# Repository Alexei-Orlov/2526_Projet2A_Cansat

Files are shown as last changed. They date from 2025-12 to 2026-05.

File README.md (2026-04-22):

# 🛰️CanSat 2025-2026
   
> **ENSEA's CanSat team project for the 2025–2026 C'space edition**

We are a team of of second year engeneering students at ENSEA and we will attend the 2025-2026 edition of the CanSat competition. CanSat competitions challenge teams to design, build, and launch a can-sized (33 cl) satellite that completes scientific or engineering missions during descent.

This year's missions are listed below :

- **Main Mission (Mandatory)**
   - **Mission 1: Deployment and Landing**
       - **Integration**: The CanSat must be equipped with a parachute located inside the device, designed to deploy during flight.
       - **Deployment**: The CanSat must successfully deploy its parachute at an altitude between 75 and 90 meters.

- **Secondary Missions (Optional)**
    - **Mission 2: Downsizing**
    **Reducing** the CanSat to a 33cl format will allow the team to double its score on the technical section.

    - **Mission 3: Ground Study**
    Conduct a study of a topographical feature during the flight.

    - **Mission 4: Onboard Camera**
    Record a video of the parachute deployment or the CanSat’s landing.

- **Bonus Mission**
    -  During the descent or following the landing, the CanSat may perform an additional mission. Its evaluation will be at the jury's discretion. It must be validated by the controllers during the RCE1 to ensure compliance with the rules.

And finally, here's the list of team members and their roles :

| Name | Role |
|---|---|
| Alexeï DOUILLARD | 3D Modeling, Satellite integration, PCB |
| Juan Pablo BARONA CIFUENTES | Embedded systems, firmware |
| Ted KOYAZANDE | Ground Station, Communications |
| Amr TAOUIS | PCB Design and testing |
| Abdelmoughit HAJJI LAAMOURI | Code |

---

## 📋 Objective 

We then defined our own objectives based on the missions we chose to fulfill among the previously mentionned missions. 

- **Main Mission (Mandatory)**
  - Devise a kirigami inspired drogue chute which will act as a protective cap on the CanSat. It will be used to deploy the main parachute. The drogue chute will be released thanks to a string and an elastic band tied to a servomotor we want to test it with the help of a homemade wind tunnel.

- **Secondary Missions**
  - **Mission 2** : Downsizing
    - Fit everything under a 330mL limit and a 350g limit using a 6 layered PCB and a super lightweight parachute
  
  - **Mission 3** : Ground study
    - **Plan A** : (Currently active)
      Use a 100m time of flight (TOF) sensor to map the ground.
      Induce a rotation thanks to an helicoïdal-shaped can.
      Precisely place the mapped point with the help of an Inertial Measurment Unit (IMU) and a barometer. The wind tunnel will also help desinging the shape of the can to see if it spins.
    - **Plan B** :
      Use a high resolution camera to film the whole descent
      Create a topological map thanks to an AI after the mission.
  - **Mission 4: Onboard Camera**
    - Record the landing using a small independent mini camera.
- **Bonus Mission**
  - Display some of the recorded data of the descend to the ground station within the transmition rate of our LoRa module.

## 🔧 Development

The development section is divided in 4 parts:
- Block diagram
- Explanation of components
- Technical sections
- Used software

So first, it's required to show the Block diagram of the solution to understand how the project is being developed.

### 💡 Block diagram of the solution

<div align="center">
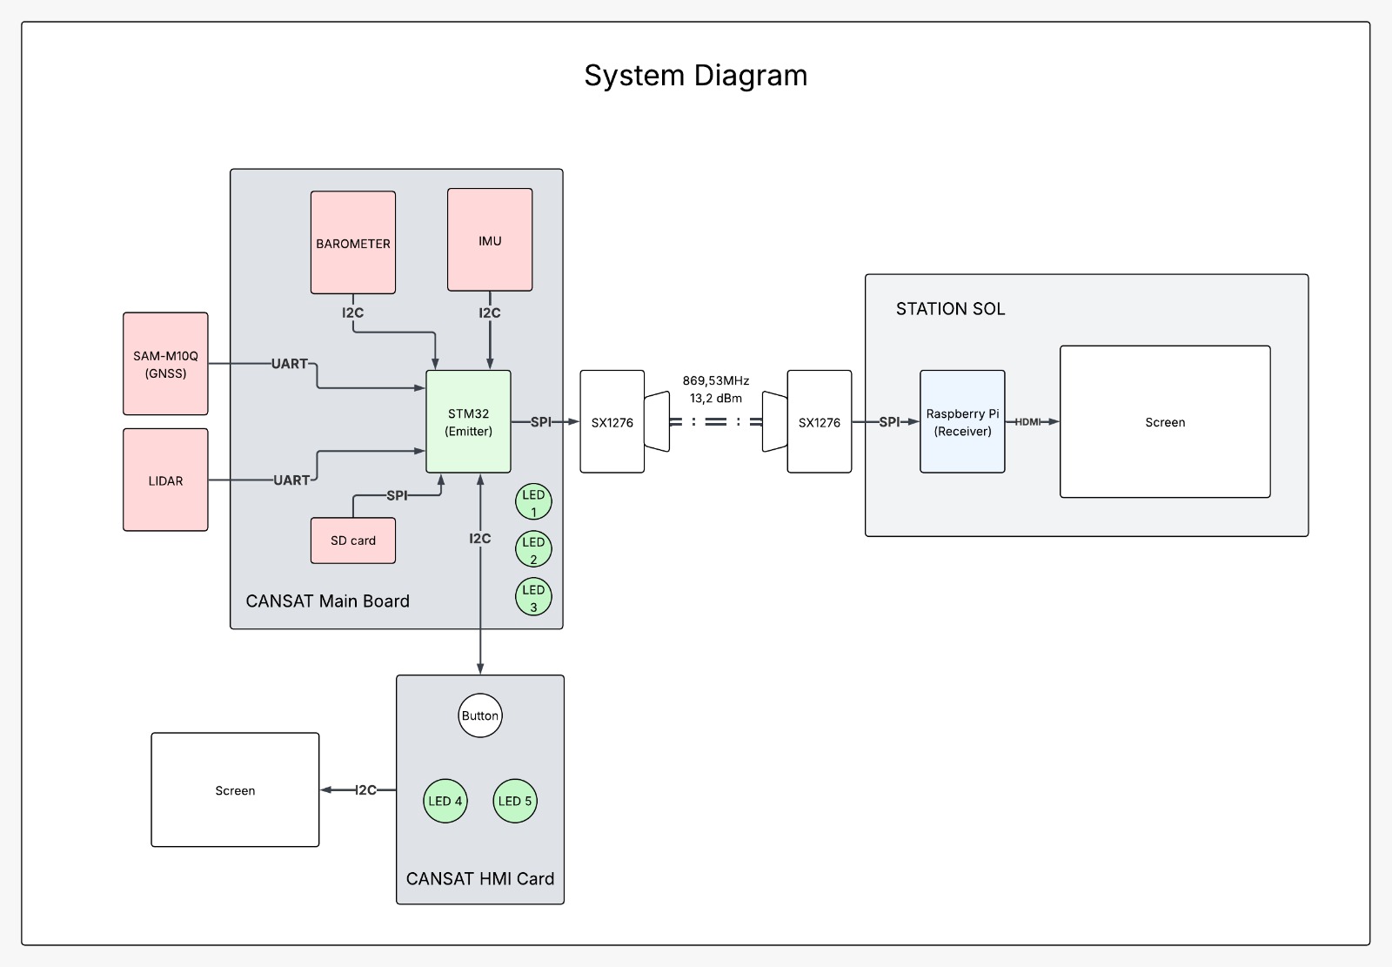
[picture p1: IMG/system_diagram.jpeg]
System Diagram
  <br><br>
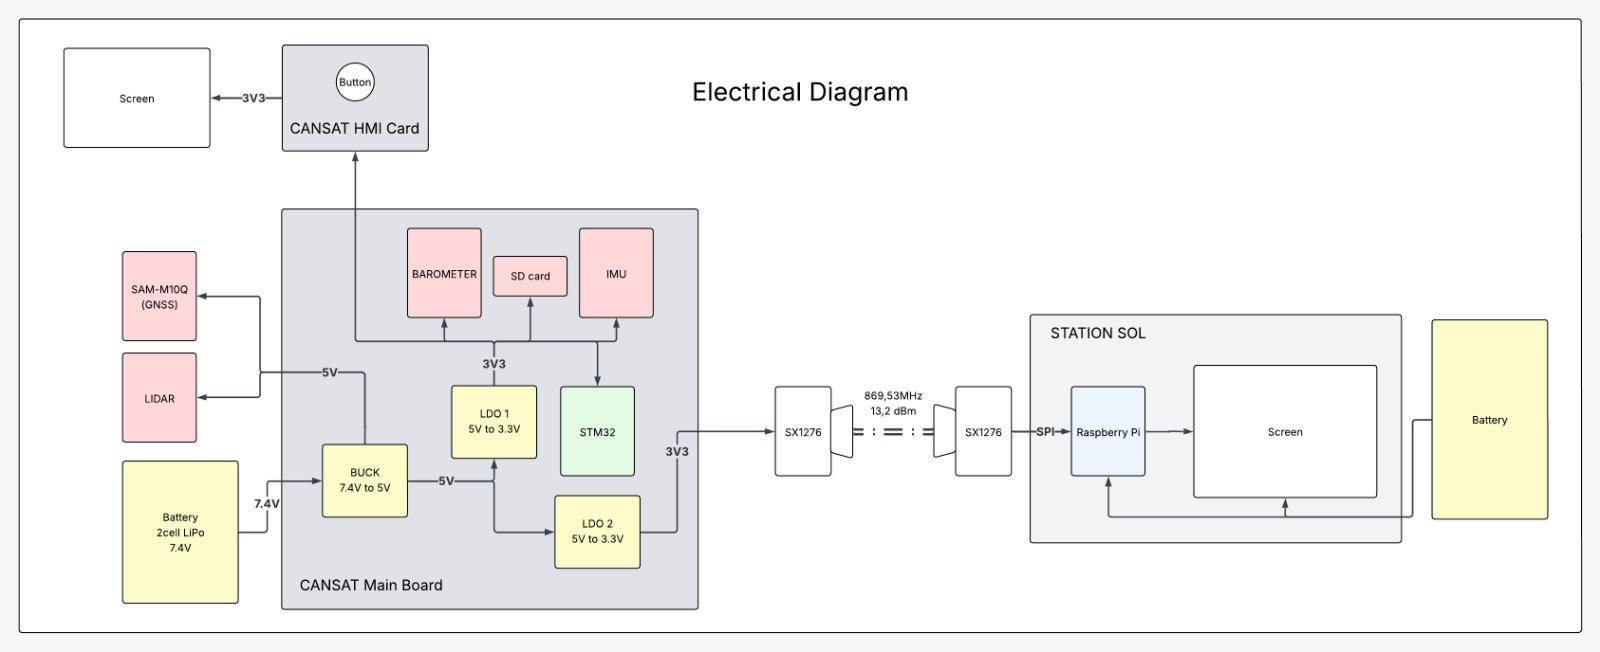
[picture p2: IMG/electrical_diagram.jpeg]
Electrical Diagram
  
</div>

### 🔗 Used components description

All the blocks shown above will be implemented with the components listed below.

| Component | Reference | Description | Justification |
| :--- | :--- | :--- | :--- |
| **LoRa Module** | SX1276 | The SX1276/77/78/79 transceivers feature the LoRaTM long range modem that provides ultra-long range spread spectrum communication and high interference immunity whilst minimising current consumption. | Long range communications were required with a solid reliable interface, also it was recommended by last year’s CANSAT team from the school. | On the Mainboard PCB
| **LiDAR Altimeter** | LW20/C | A compact, IP67-rated laser altimeter from LightWare. It provides high-precision distance measurements up to 100 meters using time-of-flight technology, capable of multiple returns. | It allows accurate terrain mapping to accomplish one of the missions. |
| **Microcontroller (MCU)** | STM32G431CBU6 | A 32-bit ARM Cortex-M4 microcontroller by STMicroelectronics. It features mixed-signal capabilities, high-speed processing (170 MHz), and hardware mathematical accelerators (CORDIC/FMAC). | High processing speed is required for sensor fusion and real-time control loops, handling data faster and more efficiently than standard beginner boards. |
| **Barometer** | BMP581 | A high-precision absolute barometric pressure sensor. It is designed for mobile applications, offering low noise and low power consumption to measure atmospheric pressure. | Determining altitude and vertical velocity (descent rate). It is critical for triggering parachute deployment based on pressure changes. Also recommended from last year’s project. |
| **IMU (Inertial Measurement Unit)** | BNO055 | A 9-axis System in Package (SiP) integrating a triaxial 14-bit accelerometer, a triaxial 16-bit gyroscope with a range of ±2000 degrees per second, and a triaxial geomagnetic sensor. It includes a dedicated microcontroller for sensor fusion. | Provides orientation data (Euler angles, Quaternions) directly. The on-board sensor fusion offloads complex math from the main MCU, ensuring accurate angular position estimation. |
| **GNSS Module** | SAM-M10Q | A patch antenna module from u-blox featuring the M10 standard precision GNSS platform. It supports concurrent reception of four GNSS constellations (GPS, GLONASS, Galileo, and BeiDou). | Required for tracking the CanSat's trajectory and lateral movement. The concurrent reception ensures a faster "time-to-first-fix" and better positioning accuracy. Also provides redundancy for altitude estimation. |
| **Voltage Regulator (LDO)** | LDO40LPU33RY | A high-precision, low-dropout voltage regulator from STMicroelectronics. It provides a stable output with low quiescent current and low noise. | Used to provide a clean, stable 3.3V power line to sensitive electronics (like the MCU and sensors) filtering out noise that might come from the main power rail. |
| **Local Storage** | Micro SD Card + Molex 473092651 | A standard high-capacity non-volatile flash memory storage card interfaced via SPI or SDIO with the Molex 473092651 card reader. | Used to save a large amount of points and telemetry from the different sensors. It will be recording everything and setting timestamps on measurements. This will be the data that is recovered post-flight. |
| **Single Board Computer** | Raspberry Pi (Model 4 / Zero 2 W) | A low-cost, credit-card-sized computer that plugs into a computer monitor or TV, and uses a standard keyboard and mouse. It runs a Linux-based operating system. | Utilized for the Ground Station architecture. It processes the incoming telemetry stream, handles the graphical user interface (GUI) for data visualization, and stores mission logs. |
| **Battery** | 2-Cell LiPo (7.4V) 2 x 500mAh| A Lithium Polymer rechargeable battery pack consisting of two cells in series, providing a nominal voltage of 7.4V and high discharge capabilities. | The 7.4V output is ideal for the input range of the voltage regulators, providing sufficient overhead to maintain stable power throughout the mission duration. |
| **Buck Converter** | LMR51625 | A wide-input, synchronous buck converter from Texas Instruments. It is designed to regulate high voltage inputs down to lower logic levels with high efficiency and a compact footprint. | Steps down the 7.4V battery voltage to 5V efficiently. Unlike linear regulators, this switching regulator minimizes heat generation and power loss. |
| **JST Connectors** | JST SH Vertical| Small plugin connector we used sizes from 3 to 7 pins, Thanks JST for the samples ! | All of our components are connected thanks to JST SH connectors these are a good compromise between compactness and ease of use |
| **Camera** | Drone camera| Camera module stolen from a drone with 2.4GHz reciever and SD card reader plugged to another 500mAh 3.4V battery | We found 2 very similar HD cameras from cheap drones however one only works via a wifi app and the other one via UART|
### 🔌 Electronic design
#### Mainboard PCB
The electronic architecture of the Vortex project is based on a “reverse engineering” process. Indeed, by analyzing and understanding last year’s project and more precisely last year’s PCB, we were able to identify the key points of the PCB and the components that needed to be modified. Due to this process, we chose all the components listed above to meet the evolving requirements of our missions and did the schematic.

<div align="center">
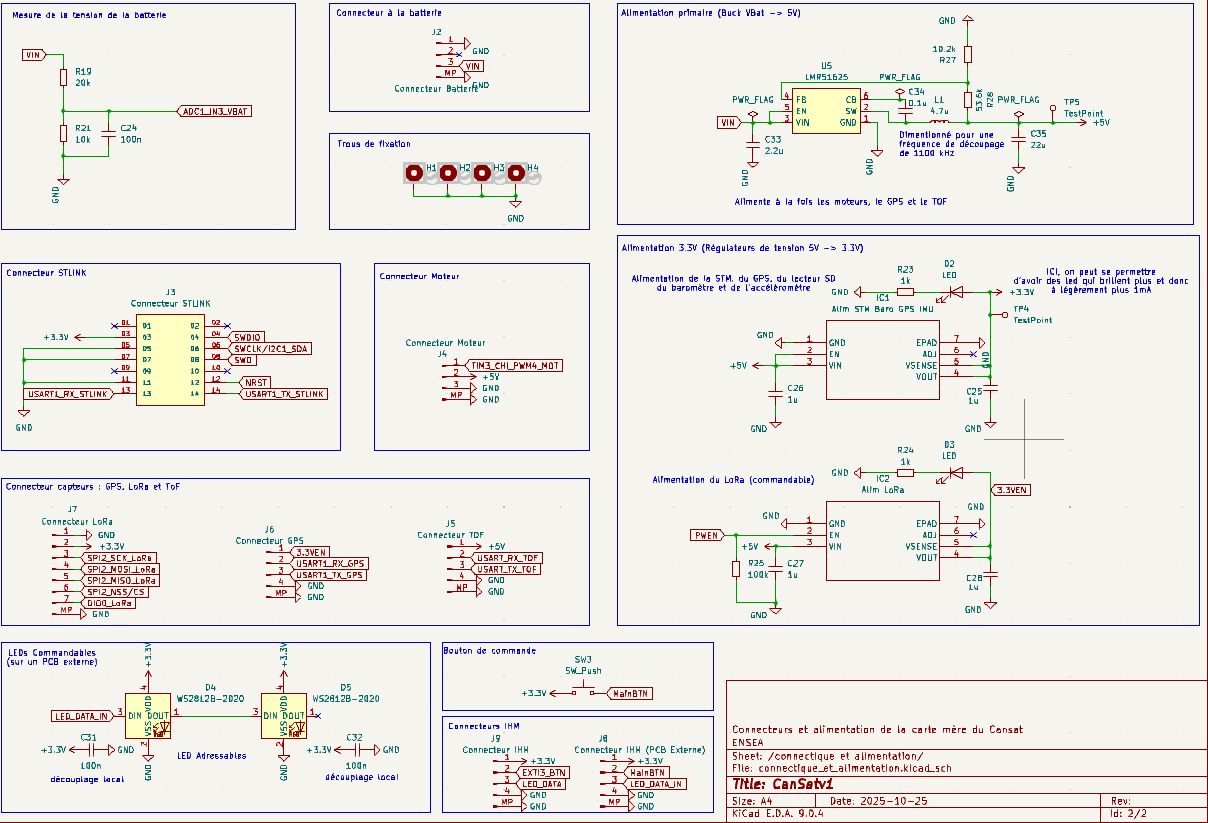
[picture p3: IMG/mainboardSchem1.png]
Schematic 1
  <br><br>
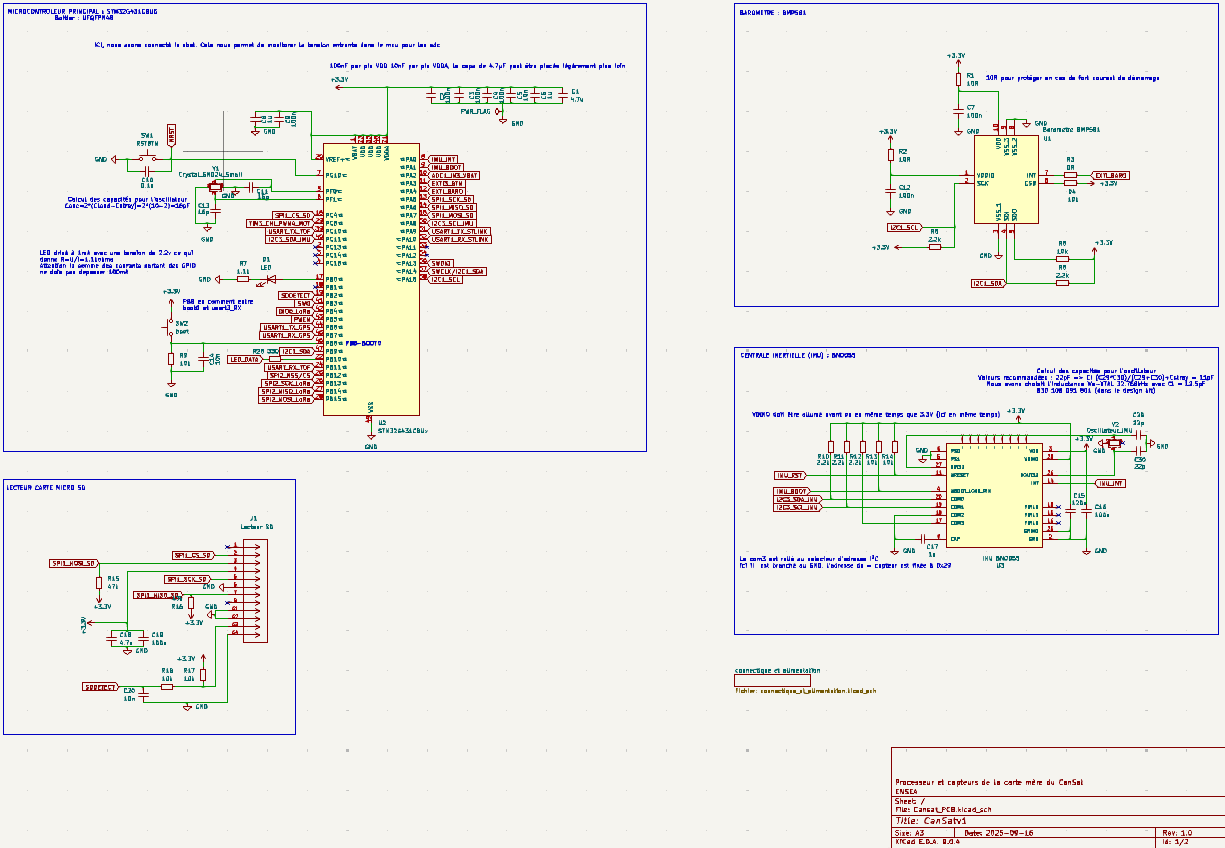
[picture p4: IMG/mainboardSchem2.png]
Schematic 2
  
</div>

To integrate this high quantity of components within the restricted 33cl volume of the can, we developed a 6-layer PCB. The layers are organised as follows : 
1. Signal
2. GND
3. Signal
4. PWR
5. GND
6. Signal

Here is the final PCB :

<div align="center">
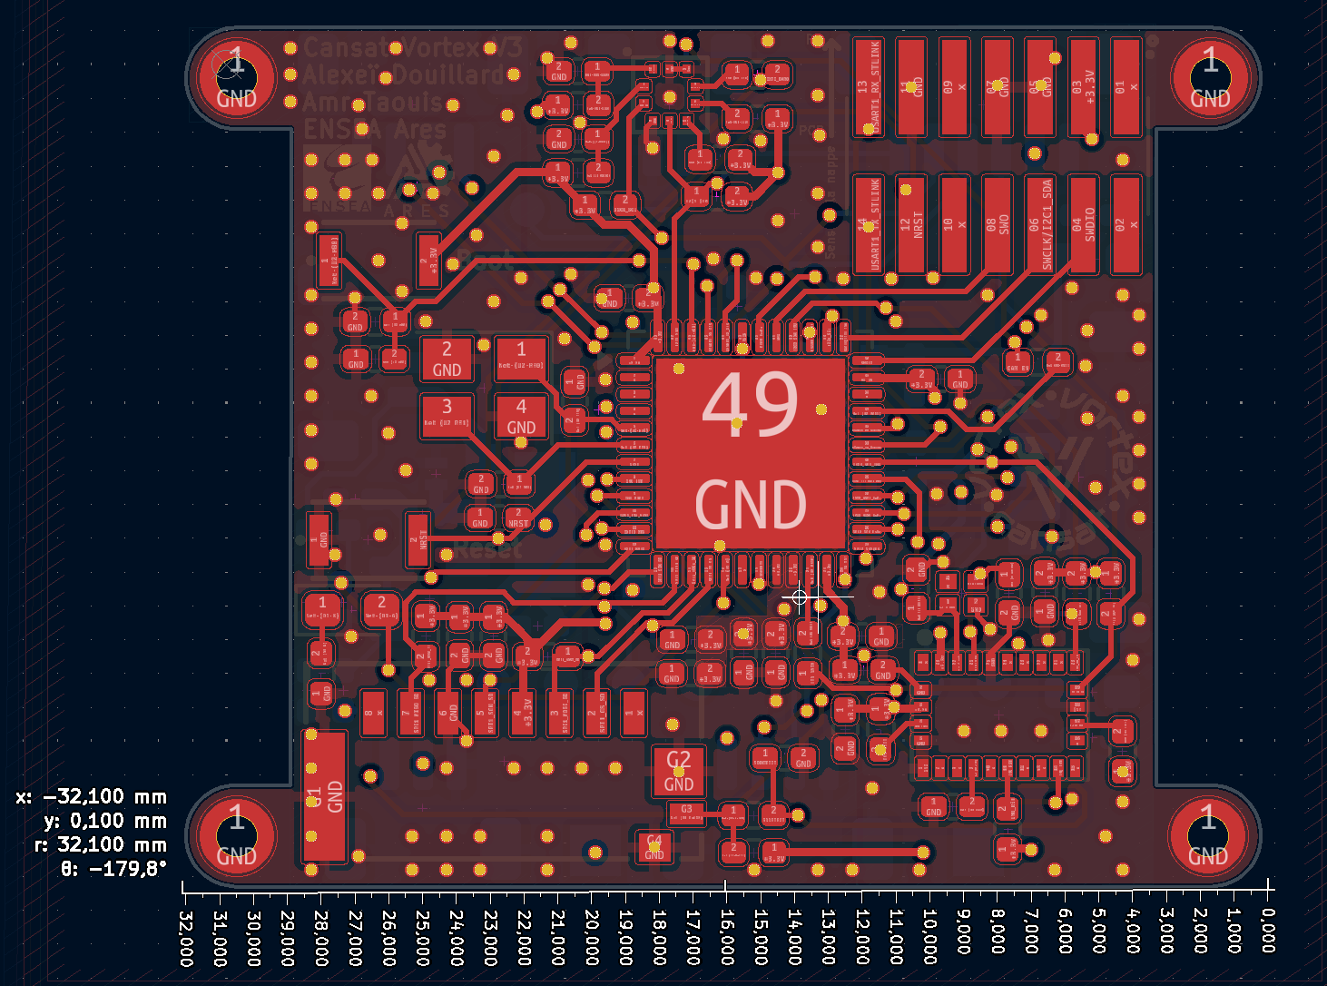
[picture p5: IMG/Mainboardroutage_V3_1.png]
Mainboard Top
  <br><br>
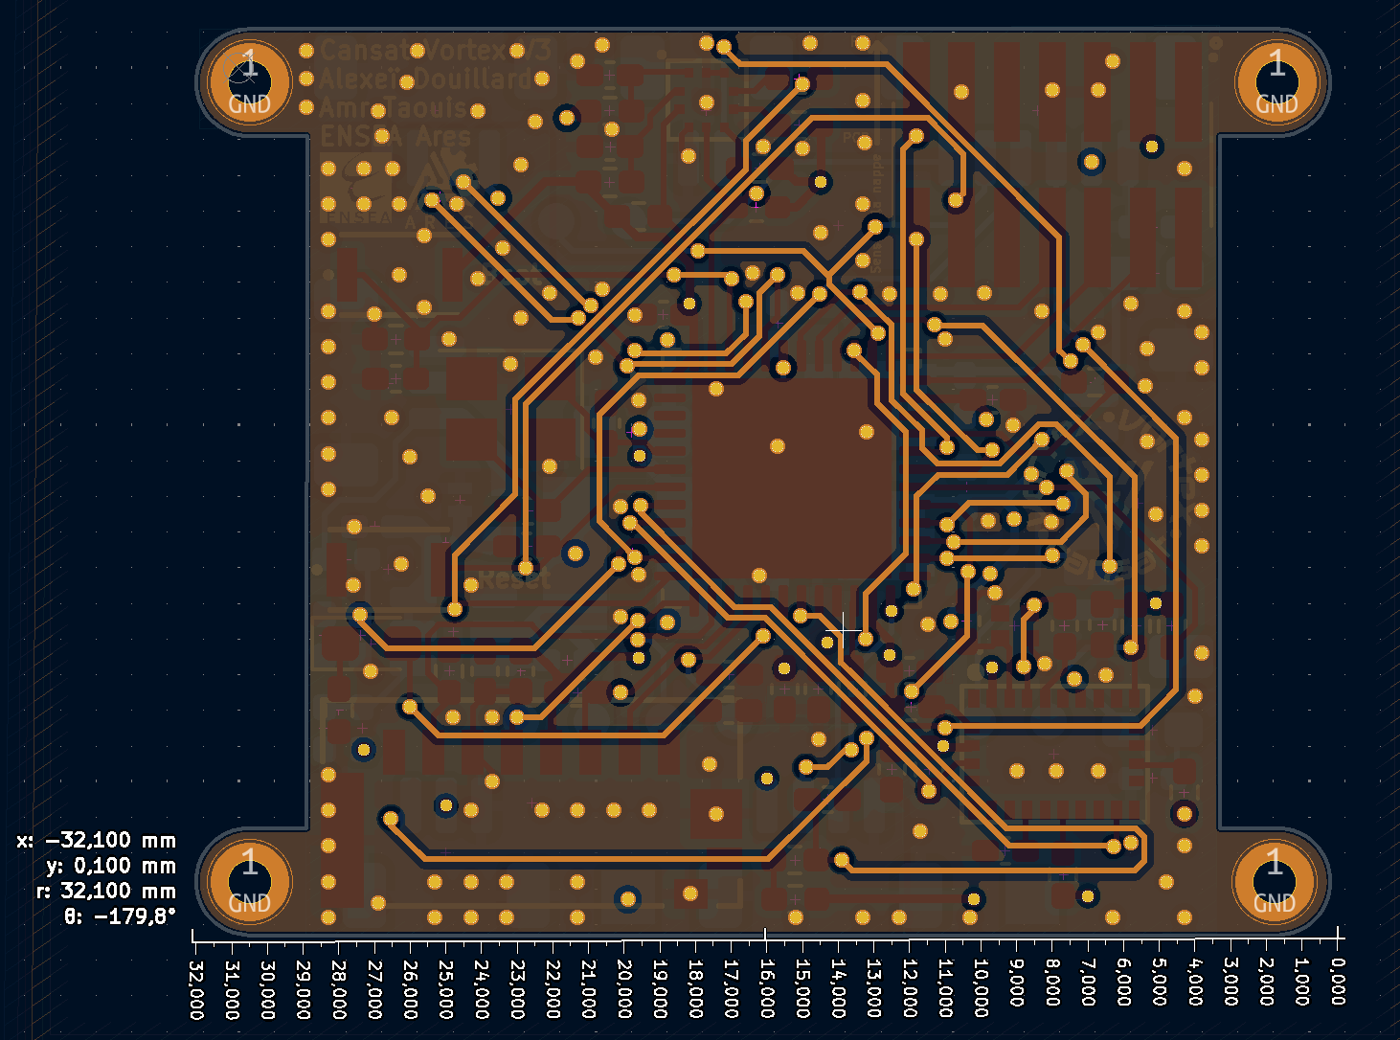
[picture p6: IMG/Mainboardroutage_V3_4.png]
Mainboard Internal
  <br><br>
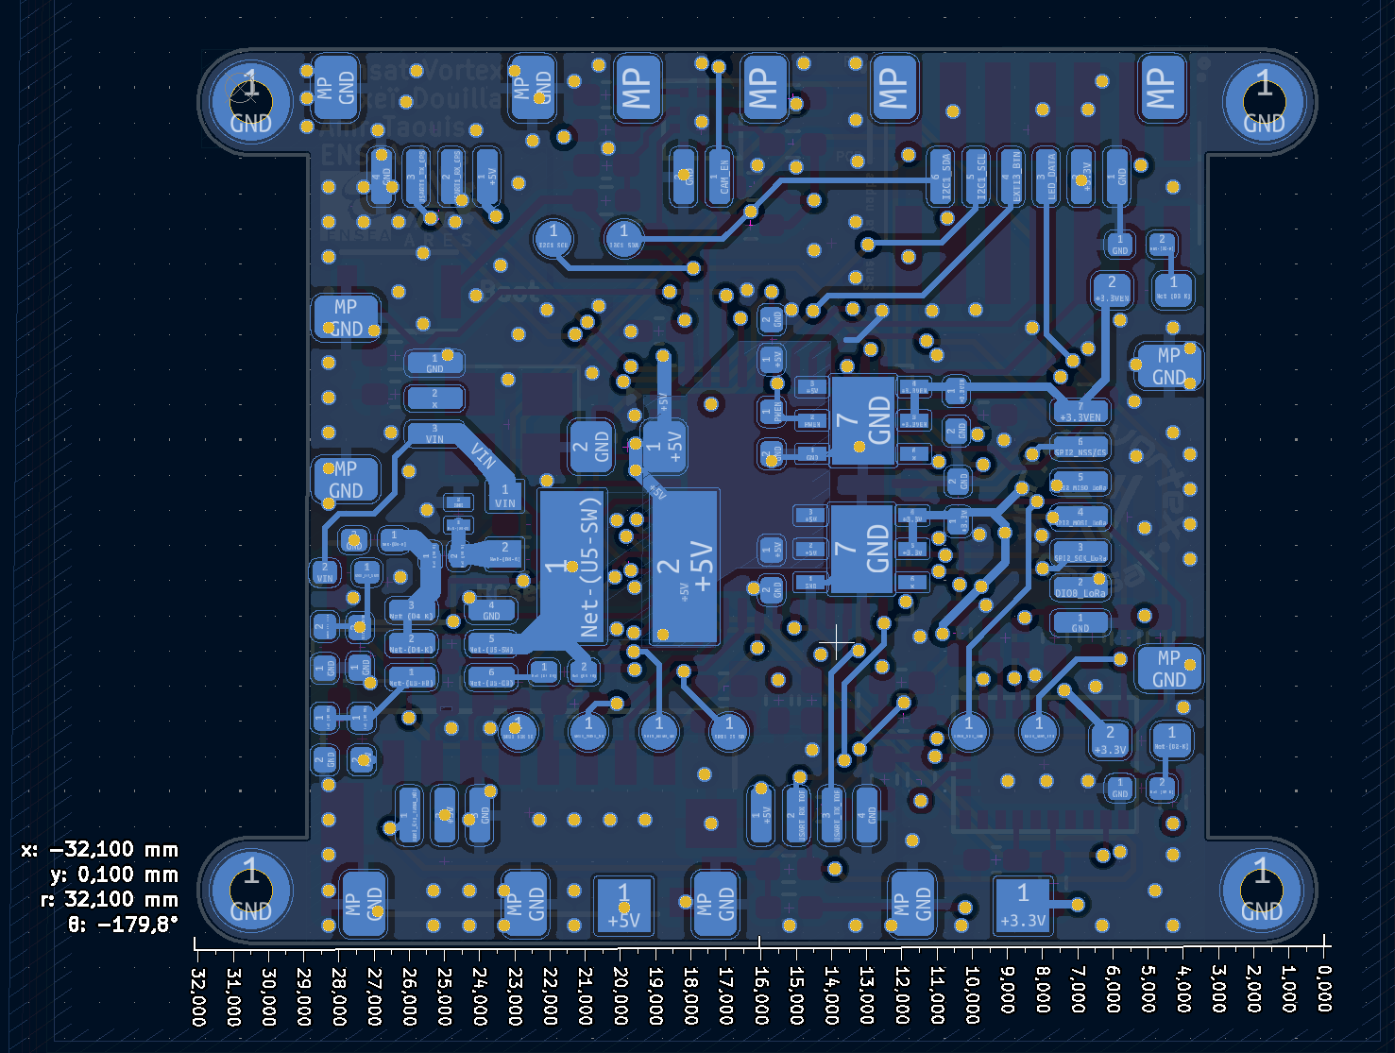
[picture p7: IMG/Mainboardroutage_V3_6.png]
Mainboard Bottom
  
</div>

Here are the rendered 3d model of our PCB :

Front side : STM32 (center), Barometer (top), JTAG connector (top right), IMU (bottom right), SD card reader (bottom left), Status LED (left), Buttons (left), 
Whe have two oscillators; a 12 MHz clock for the STM on it's left and a 32.765 kHz clock for the IMU above the IMU.

<div align="center">
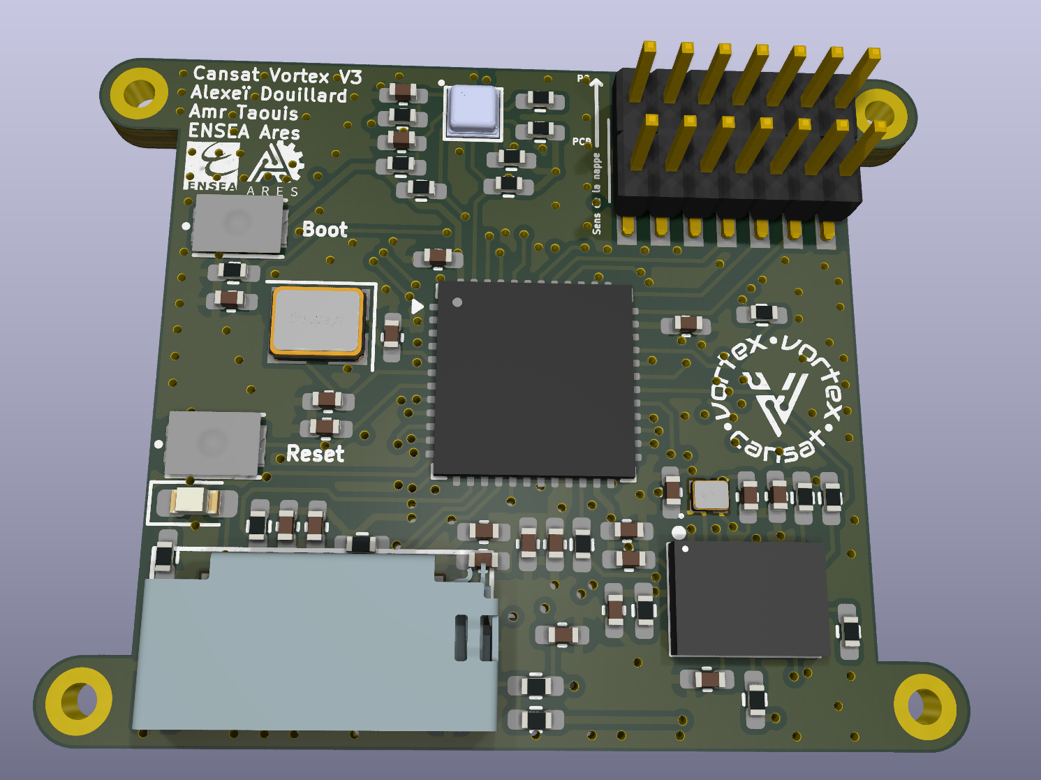
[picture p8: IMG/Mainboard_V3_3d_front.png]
Front side
  
</div>

Back Side :
Vbat -> 5V Buck (top left), Main 3.3V LDO (center right), and 3.3V LDO for the LoRa module with an enable function (bottom left), Connectors to the external modules :
- Motor (top left)
- Time of Flight sensor (top right)
- LoRa module (right)
- HMI *see next section* (bottom right)
- GPS (bottom left)
- Battery 7.4V (right)

There are also two power testpoints, one for them is to test the 5V (top left), the other is for the main 3.3V (top right).
The other testpoints are for the onboard compoennets : SD card, IMU and barometer which pinout can be found on the Kicad project

Thee motor wasn't necessary in the end but we decided to keep it as it allowed us to implement some new features if needed

<div align="center">
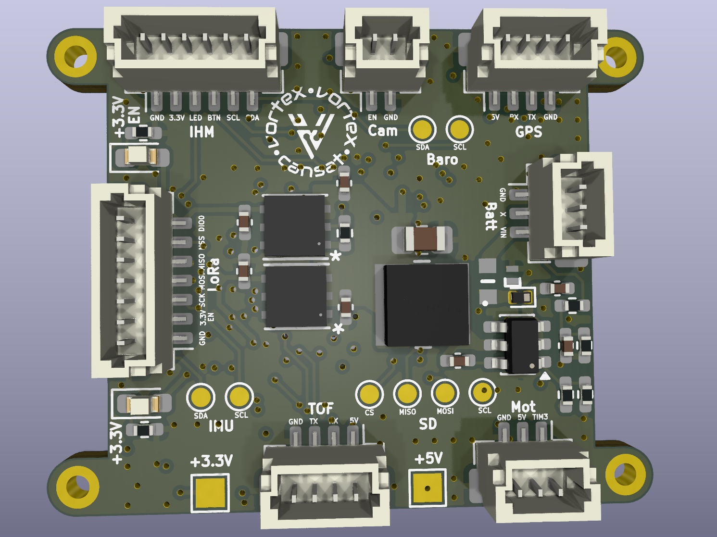
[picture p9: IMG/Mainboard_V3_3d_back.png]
Back side
  
</div>

/!\ Warning ! The V1 Has a mistake in the buck's footprint we had to rewire it manually to ensure that uit could power the rest of the mainboard.The is also a mistake in the connection of 3.3V enabeled signal, the 3.3V power supply that can be triggerd is supposed to be linked to the LoRa connector, here it has mistakenly been connected to the GPS connector.
This has been fixed in the following versions (V2) and the latest version V3 is a cleaner version with added electrical security.

The V2 and V3 are fully functionnal however some re-wiring had to be done done to implement the new UART Camera pins instead of the simple camera enable pin. The changes concern the ADC od the battery measurement system and the HMI button interrupt. 

A Blinking blue LED controlled by the microcontroller,
The red LEDs mean that the LDO are working one is on by default, the other one was activated by the microcontroller here is the blinking V1 :

<div align="center">
  Testing
</div>

#### HMI PCB
We also developed a secondary HMI (Human-Machine Interface) PCB (2 layers). This PCB establishes an I2C link with the mainboard to control an onboard status screen. Moreover, the HMI PCB contains two addressable LEDs, providing a programmable visual feedback system to monitor the CanSat’s state before and during the launch.

<div align="center">
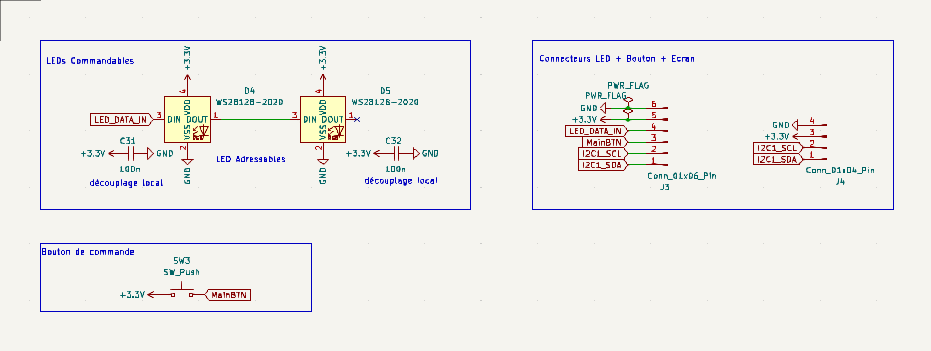
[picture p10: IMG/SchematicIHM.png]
IHM Schematic
  <br><br>
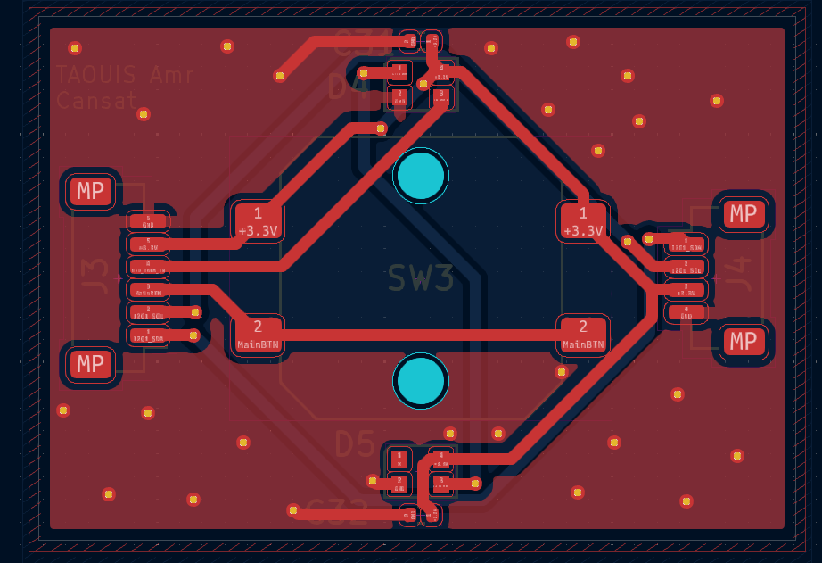
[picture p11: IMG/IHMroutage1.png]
IHM Top
  <br><br>
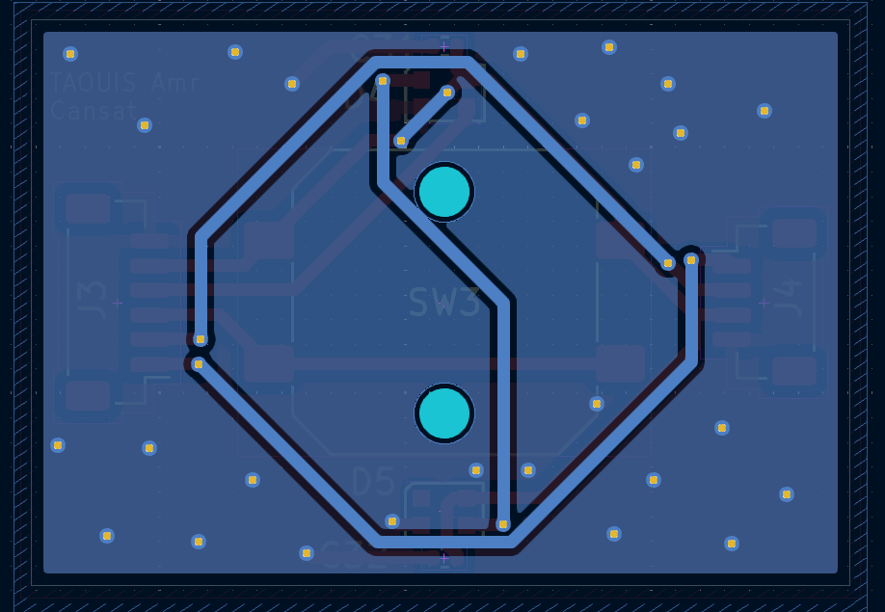
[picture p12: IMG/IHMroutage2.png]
IHM Bottom
  
</div>

The HMI PCB was tested in integration with an OLED screen and a Nucleo development board. The display correctly shows the CanSat system status (LoRa link state, battery level), and we can cycle through information screens using the onboard button. A short circuit between GND and 3.3V was detected after re-soldering a loose LED and was resolved. A custom enclosure for the HMI PCB and the OLED screen was also designed in OnShape, to hold them inside a handheld remote control casing. The next and final step for the HMI PCB is to connect it to the mainboard, which will allow the display to show the actual real-time status of the onboard components instead of test values.

<div align="center">
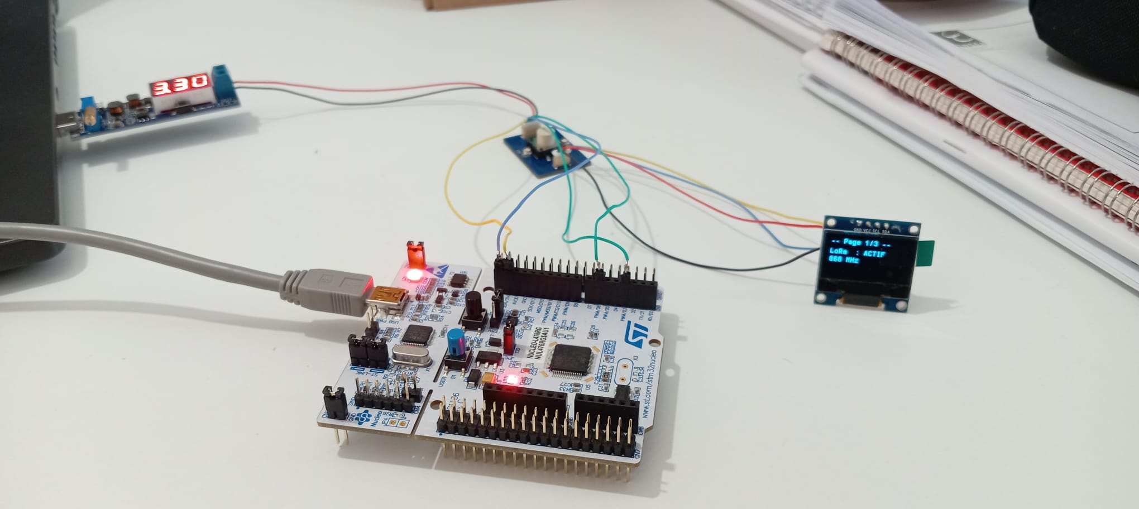
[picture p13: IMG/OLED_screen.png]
state display
  <br><br>
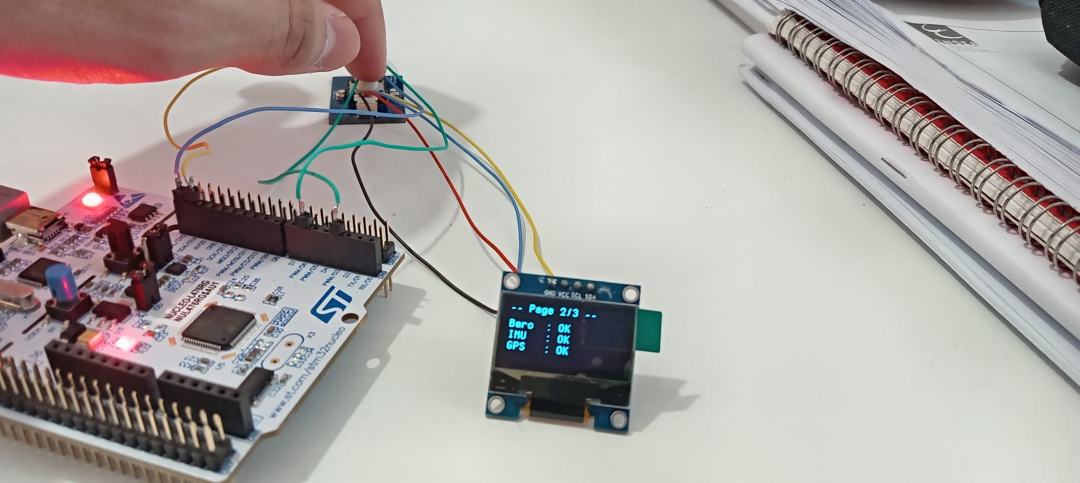
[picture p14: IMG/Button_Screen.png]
Button pushed
  <br><br>
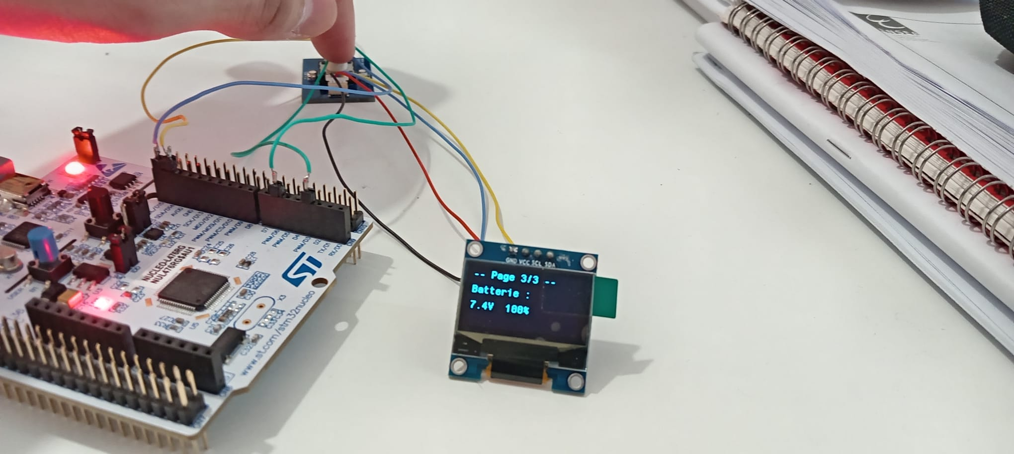
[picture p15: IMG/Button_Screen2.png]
Button pushed2
  <br><br>
</div>

### ⚙️ Mechanical Design

#### Cansat Core
Our Cansat is split in two independant parts:
-  The upper section (nicknamed "Pepe"), it has a spring loaded triple fairing opening. The fairing is kept closed by the trigger. The trigger is removed thanks to the drogue chutes to calibrate the height at wich we release the trigger we change the number of chained drogue chutes (detailed below).
- The lower section (nicknamed "Latz") holds the entire electronics skeleton (nicknamed "Gravitsappa"). The lower section is decoupled from the top with a M5 bearing. It has a spiral going all around to enduce a spin, this is the spin that allows our lidar to scan the ground in a spiral patern as the cansat falls. This is also why we have vertical fins in the upper section prevent the parachute from spinning

The following schematic can be found : [here as a pdf](./Hardware/3D_Modeling/Cansat%20Schematic%20SCAE.pdf) or [here as the onshape project](https://cad.onshape.com/documents/c1d9fbb7572429731402c7f6/w/9922ef0afe1ea96367c92f22/e/19dd7d98b534d5ce389091af) 
<div align="center">
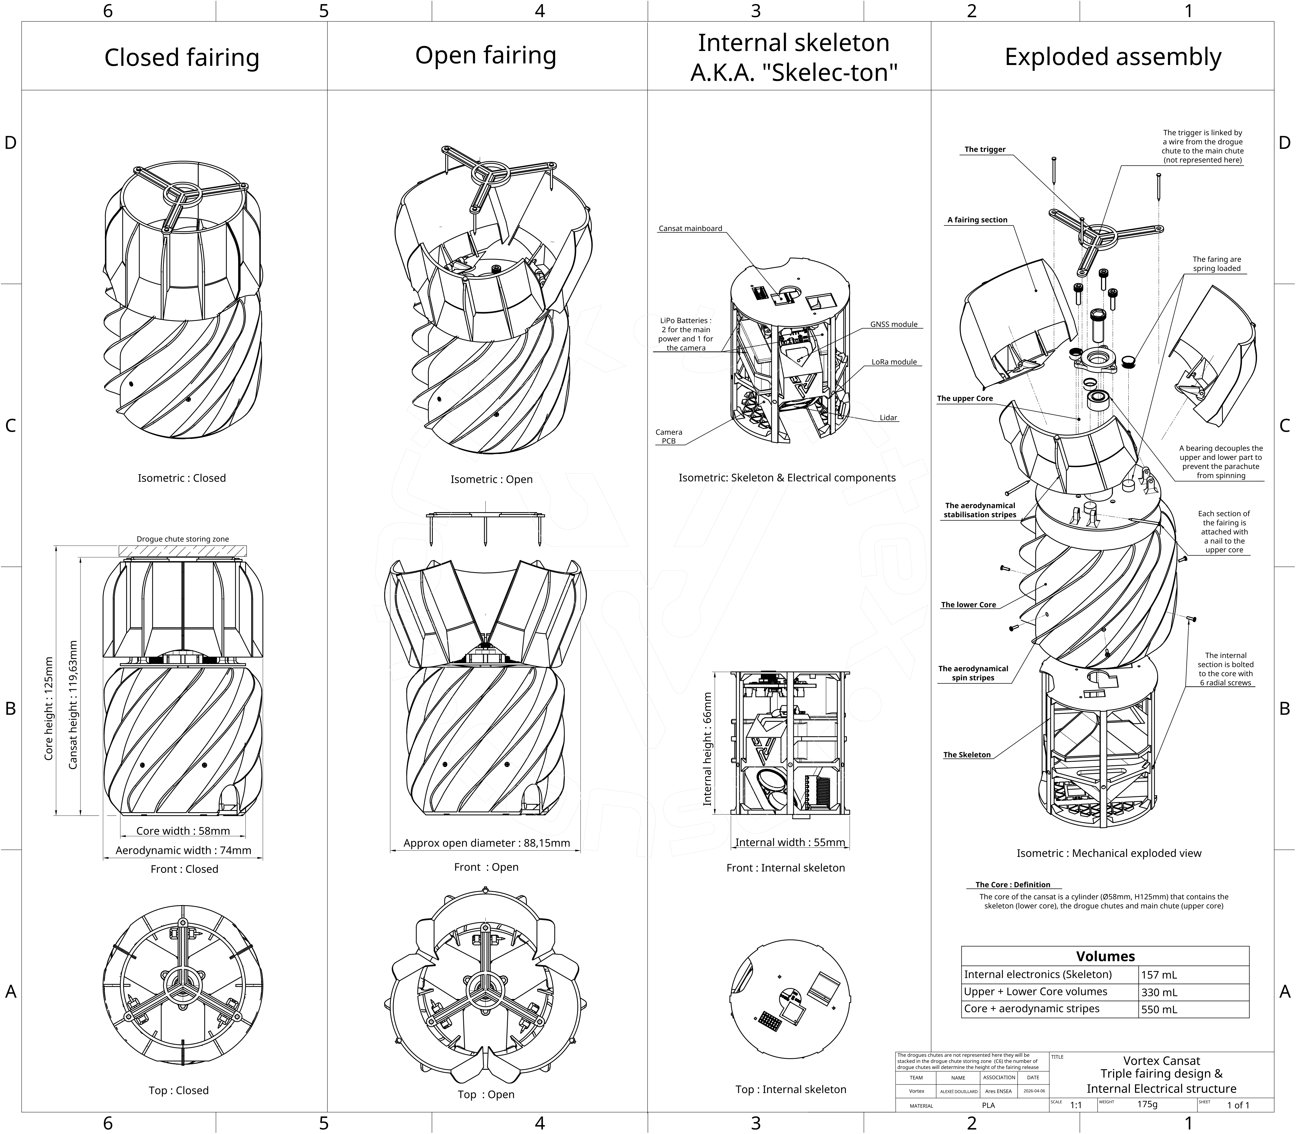
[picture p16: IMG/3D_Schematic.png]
  
</div>
<div align="center">
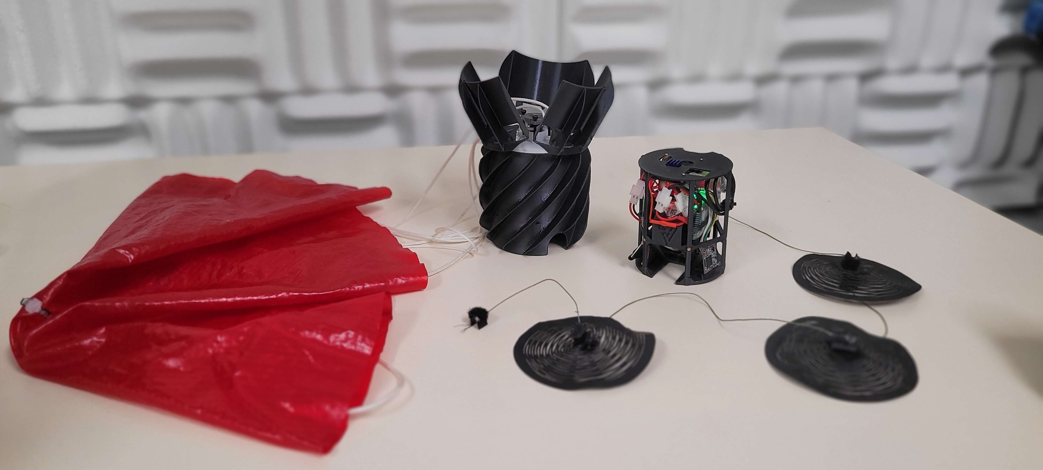
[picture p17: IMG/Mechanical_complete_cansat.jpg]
Complte assembly
  
</div>
<table style="width:100%;">
  <tr>
    <td style="text-align:left;">
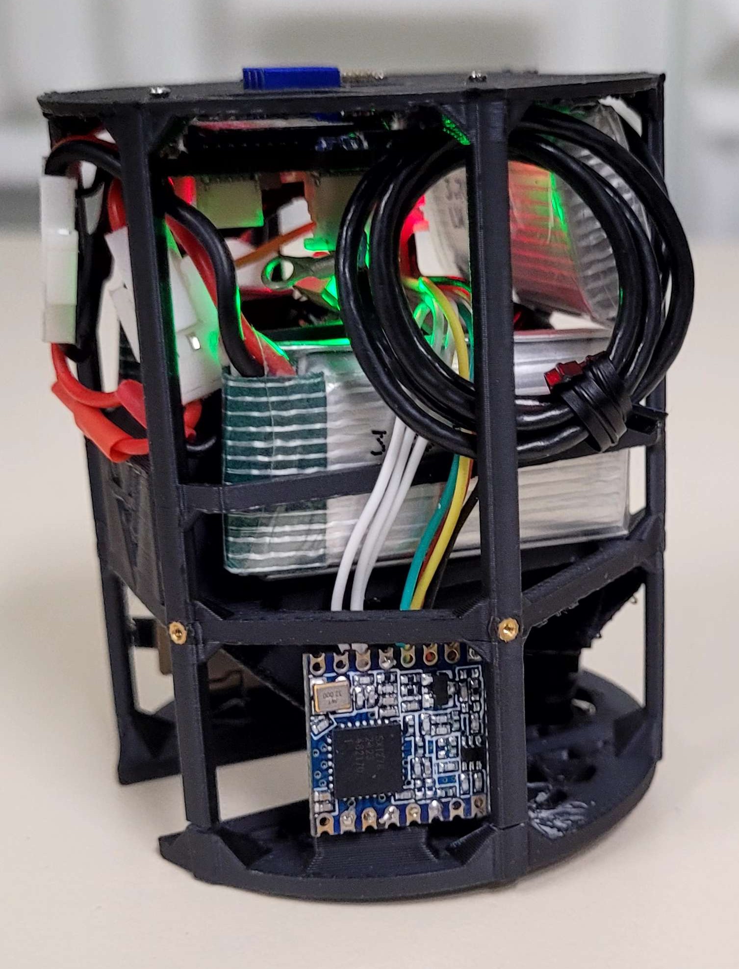
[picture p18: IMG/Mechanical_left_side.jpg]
Electrical left
      
    </td>
    <td style="text-align:center;">
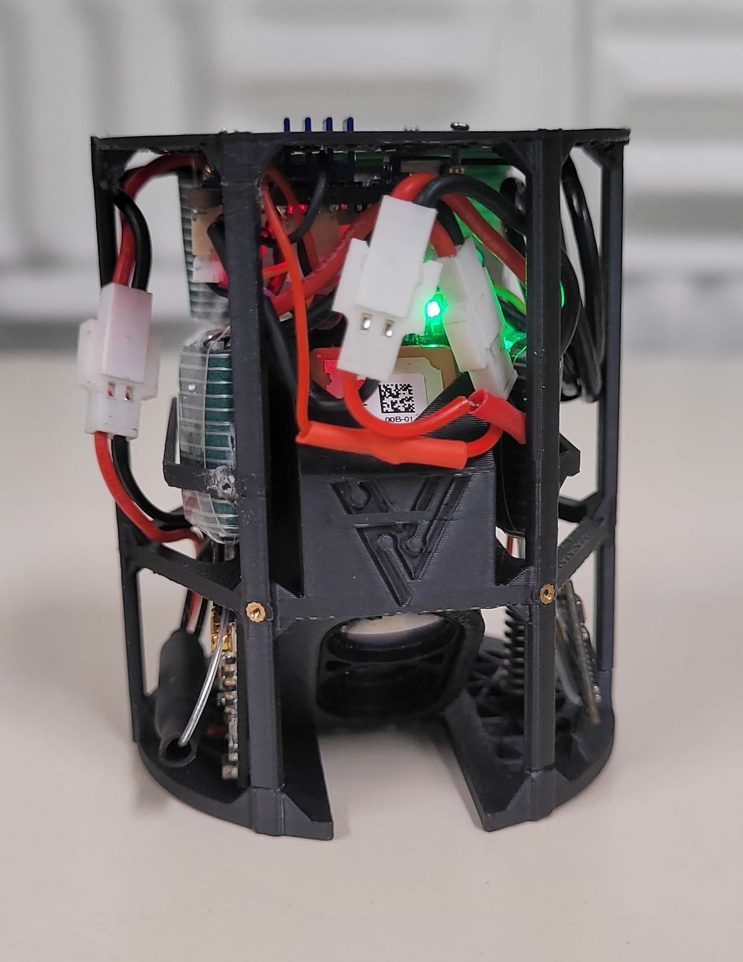
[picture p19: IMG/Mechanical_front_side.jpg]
Electrical front
      
    </td>
    <td style="text-align:right;">
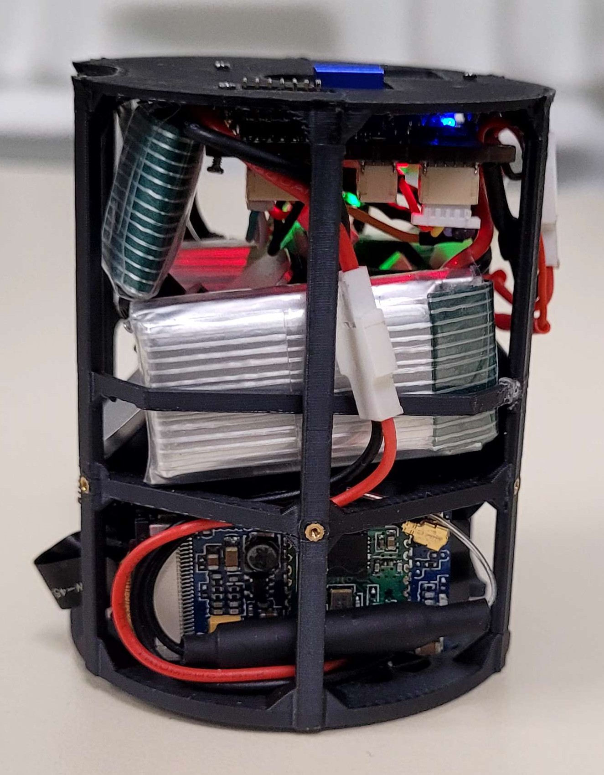
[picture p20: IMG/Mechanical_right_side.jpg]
Electrical right
      
    </td>
  </tr>
</table>

#### Drogue chutes
The drogue chute, is a kirigami inspired parachute *check the research paper in the ressources section*  we laser cutted these parachutes in a K-Way coat as we found that it had the best comprise between strenght and flexibility.

<div align="center">
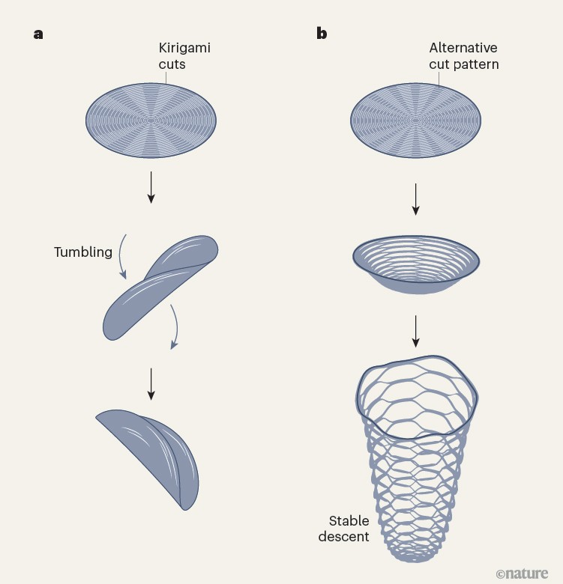
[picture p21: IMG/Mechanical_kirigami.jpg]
Kirigami example
  
</div>

Example of chained parachutes to increase the pulling force :
<div align="center">
  Chained Kirigami
</div>

#### Main parachute
The parachute dimensions were calculated using the fundamental principle of dynamics at stabilized velocity (mg = ½ρC_dSV²). By aiming at an airspeed between 2 and 5 m/s, we have found a parachute surface area of approximately 0.116 m² and a diameter of approximately 0.385 m. We have decided to take a parachute with a diameter of 45 cm. This choice has been discussed and approved by an aerospace specialist. We bought our round shapped parachute at Klima

<div align="center">
  Main parachute test
</div>

### 🧠 RTOS Software Architecture

To ensure deterministic execution, prevent data starvation, and synchronize our 3D topographical mapping, the CanSat's software is built on **FreeRTOS**. We implemented a **10Hz Unified Snapshot Architecture** where sensor data is gathered, fused, and dispatched to both the Ground Station and the onboard SD card simultaneously. 

The system is divided into four main concurrent tasks communicating safely via RTOS Queues (`qSensorEvents`, `qLoRa`, `qSDCard`):

#### 🧵 Task Management
- **`TaskFSM` (Normal Priority):** The brain of the satellite. It evaluates the flight state at 20Hz, handles LED visual feedback, and acts as the master metronome. Every 100ms (10Hz), it requests sensor readings and builds a unified `TelemetryPacket_t` to feed the communication and storage queues.
- **`TaskSensors` (High Priority):** The data gatherer. It processes hardware interrupts and I2C/UART streams to extract data from the BMP581 (Barometer with thermal feed-forward compensation), BNO055 (IMU Euler angles & Gyro), LW20/C (LiDAR distance), and SAM-M10Q (GNSS background parsing). 
- **`TaskLoRa` (Low Priority):** The communicator. Formats the unified telemetry struct into our custom `v2.3` comma-separated protocol and transmits it via the SX1276 module. It handles Standby broadcasts and guaranteed-delivery Calibration handshakes.
- **`TaskSDCard` (Low Priority):** The data logger. Utilizes the **FATFS** library over a custom low-level SPI driver to mount a MicroSD card and log a highly detailed `FLIGHT.CSV`. To prevent hardware bottlenecks during high-speed laser mapping, it uses an `f_sync()` batching algorithm, safely locking data to the silicon memory without crashing the RTOS.

#### 🔄 Finite State Machine (FSM)
The CanSat operates entirely autonomously. Flight states are evaluated dynamically based on environmental triggers detected by the sensor fusion (primarily combining the LiDAR and Barometer).

<div align="center">
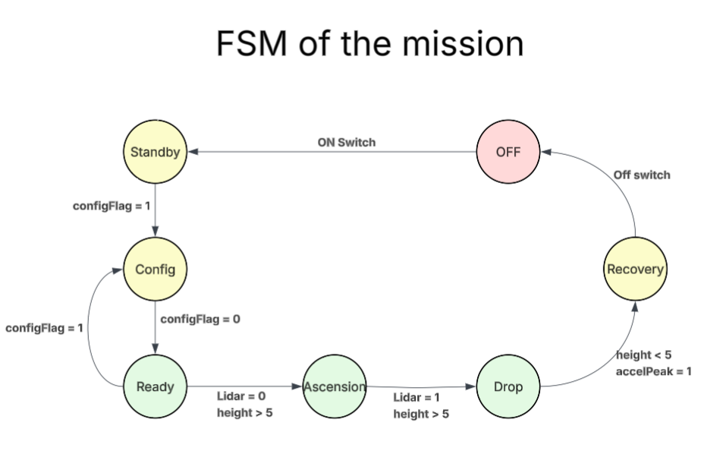
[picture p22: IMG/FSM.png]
   
</div>

<br>

| State | Name | Description | In Transition | Out Transition | Power Supply | LIDAR | Barometer | GNSS | LoRa | IMU |
| :---: | :--- | :--- | :--- | :--- | :---: | :---: | :---: | :---: | :---: | :---: |
| **OFF** | Off state | The power supply switch is in OFF, everything is without power supply. | `powerSwitch = 0` | `powerSwitch = 1` | 🔴 OFF | 🔴 OFF | 🔴 OFF | 🔴 OFF | 🔴 OFF | 🔴 OFF |
| **S0** | Standby | Idle mode, waiting for config. Rest mode, low consumption. | `powerSwitch = 1` | `conFlag = 1` | 🟢 ON | 🔴 OFF | 🟢 ON | 🟢 ON | 🔴 OFF | 🔴 OFF |
| **S1** | Config | Configuration mode after connecting status interface. Waiting until unplugged. | `conFlag = 1` | `conFlag = 0` | 🟢 ON | 🟢 ON | 🟢 ON | 🟢 ON | 🟢 ON | 🟢 ON |
| **S2** | Ready | Waiting for the ascension or Configuration. | `conFlag = 0` | `lidar = 0` and `height > 5` | 🟢 ON | 🟢 ON (Low Power) | 🟢 ON | 🟢 ON | 🟢 ON | 🟢 ON |
| **S3** | Ascension | Ascending state, the device will be waiting for the drop. | `lidar = 0` and `height > 5` | `lidar = 1` and `height > 5` | 🟢 ON | 🟢 ON (Low Power) | 🟢 ON | 🟢 ON | 🟢 ON | 🟢 ON |
| **S4** | Drop | Descent state, all the sensors are ON. High consumption. | `lidar = 1` and `height > 5` | `height < 5` | 🟢 ON | 🟢 ON | 🟢 ON | 🟢 ON | 🟢 ON | 🟢 ON |
| **S5** | Recovery | Final steady state, waiting for recovery and data extraction. | `height < 5` | `powerSwitch = 0` | 🟢 ON | 🔴 OFF | 🔴 OFF | 🟢 ON | 🟢 ON | 🔴 OFF |

### 📊 Data Acquisition & Routing Flow

The CanSat's data pipeline is designed to be asynchronous, modular, and highly reliable. Data is gathered from four distinct hardware sensors across different communication buses, packaged into independent C-structures, and finally routed to our two main storage and transmission endpoints.

Here is the breakdown of the data acquisition architecture:

#### 1. Sensor Inputs & Protocols
The system continuously listens to four hardware interfaces:
* **GNSS (UART):** Receives continuous NMEA frames from the satellites.
* **Barometer (I2C):** Polled for highly precise atmospheric pressure and temperature.
* **IMU (I2C):** Polled for the onboard sensor-fused orientation and acceleration.
* **LIDAR (UART):** Receives high-speed distance measurements via time-of-flight laser pulses.

#### 2. Data Encapsulation (The Structs)
To keep the data organized and synchronized, each sensor's readings are immediately packed into a dedicated `struct`. Every struct includes a dedicated **timestamp string** captured the exact millisecond the data was read, ensuring perfect synchronization for post-flight analysis.

* **GNSS Struct:** `timestamp`, `latitude`, `longitude`, `altitude`, `satellites`
* **Barometer Struct:** `timestamp`, `height`, `temperature`
* **IMU Struct:** `timestamp`, `head` (yaw), `pitch`, `roll`, `accelX`, `accelY`, `accelZ`
* **LIDAR Struct:** `timestamp`, `distance`

#### 3. Data Destinations
Once the individual structures are populated, the FSM (Finite State Machine) gathers them into a single, unified master packet (`TelemetryPacket_t`). This unified snapshot is then dispatched simultaneously to two endpoints:

* 📡 **LoRa Module:** The data is serialized into a comma-separated string (our custom `v2.3` protocol) and broadcasted over the air at 10Hz to the Python Ground Station for real-time monitoring.
* 💾 **SD Card:** The exact same data is routed to the onboard FATFS SD Card via SPI. It is logged as a CSV file and locked into the physical silicon (`f_sync`) continuously, ensuring no data is lost upon impact.

### 📡 Communications & Software Architecture

The software and communication architecture of the Vortex project was developed with a primary focus on data integrity and link stability, treating the telemetry stream as the mission's critical lifeline. Following a reverse-engineering analysis of the previous team's communication structure, we opted to rebuild the data transmission system to improve packet efficiency and error handling. The solution was implemented with SX1276 module shown above. To ensure the reliability of the received data, we integrated a Cyclic Redundancy Check (CRC) mechanism, which validates packet integrity before parsing begins at the Ground Station.

On the navigation front, the software driver for the SAM-M10Q GNSS module was designed to parse specific NMEA frames (GNGGA, GNGSA, and GNRMC) to extract 3D positioning, velocity, and satellite data. We used the u-center2 software for initial configuration, enabling SBAS/EGNOS support to maximize positioning accuracy. Testing has been iterative, moving from indoor functional verification to long-range outdoor link tests to validate the link budget.
- **Summary**

  - **Robust LoRa Protocol**
  - **Error Handling:** Implemented CRC (Cyclic Redundancy Check) and header validation to automatically discard corrupted frames at the Ground Station.
  - **Handshaking:** Established a connection verification sequence ("CANSAT OK") to confirm receiver readiness before mission start.

- **Advanced GNSS Integration**
  - **NMEA Parsing:** Configured the STM32 to parse specific NMEA sentences:
  - **GNGGA:** Global Position (Latitude, Longitude, Altitude).
  - **GNRMC:** Recommended Minimum Navigation Information.
  - **GNGSA:** DOP and active satellites.
  - **Accuracy Optimization:** Activated SBAS/EGNOS support via u-center2 to enhance vertical and horizontal precision.

- **Testing & Validation**
  - **GNSS Precision:** Conducted comparative tests between indoor (cold start) and outdoor environments to verify "Time-To-First-Fix" and coordinate stability. Confirming that outdoors' performance is better.
  - **Range Testing:** Performed Line-of-Sight (LoS) tests between the CanSat emitter and Ground Station receiver to validate the LoRa link budget and antenna performance at distance.

**Current Status:** Finalizing the integration of the IMU values into the main telemetry stream.

### 🧰 Ground Station (Mission Control Center)

<div align="center">
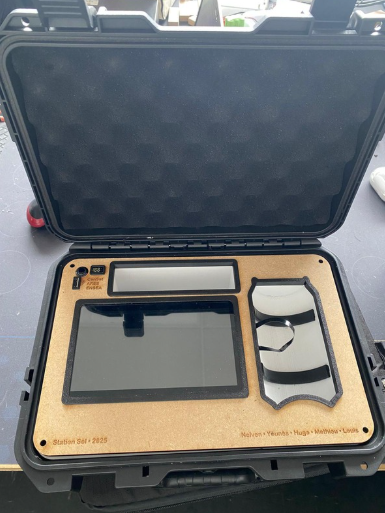
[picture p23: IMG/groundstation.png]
Ground Station Setup
  
</div>

The Ground Station serves as the mission's central command and telemetry hub, engineered for high-performance data acquisition and real-time situational awareness. It is a portable, ruggedized unit built upon a **Raspberry Pi 5** single-board computer.

#### **Communication & Data Link**
The station utilizes a **LoRa SX1276** transceiver operating on the **869.53 MHz** frequency. The link is governed by a custom **v2.4 telemetry protocol**, processing 17-field packets to monitor critical flight metrics including 9-axis IMU data, GNSS coordinates, and atmospheric conditions. To ensure data integrity, the system implements hardware-level SPI communication and software-side CSV logging (`flight.csv`) for redundant storage.

#### **Real-Time Visualization Suite**
The Ground Station software is an asynchronous, multi-threaded **PyQt5** application designed for low-latency monitoring:
* **3D Kinematic Rendering**: Uses **PyOpenGL** to visualize the satellite's orientation in real-time by mapping incoming Euler angles to a custom STL model.
* **Dynamic Geospatial Tracking**: Features an optimized **OpenStreetMap (OSM)** tile map engine (Zoom 18) that handles position updates in less than 1ms using pre-fetched memory caching.
* **Telemetry Analytics**: Provides real-time plotting via **PyQtGraph**, calculating derivative metrics such as vertical speed and applying a 12-sample moving average for battery voltage smoothing.
* **Mission State Monitoring**: Displays real-time flight phase indicators (Calibration, Ascension, Drop, Recovery) based on sensor-fusion bitmasks.

Detailed specifications regarding the software architecture, SX127x register configurations, and the post-flight signal processing pipeline (FFT, Kalman filtering, and LIDAR point cloud fusion) can be found in the **[README_GUI.md](./README_GUI.md)**.

### 🍃 Wind Tunnel

For reliably testing the parachute we constructed a wind tunnel that uses two 350W conter-rotative brushless drone motors. This will ensure we have no undesired vorteces

<div align="center">
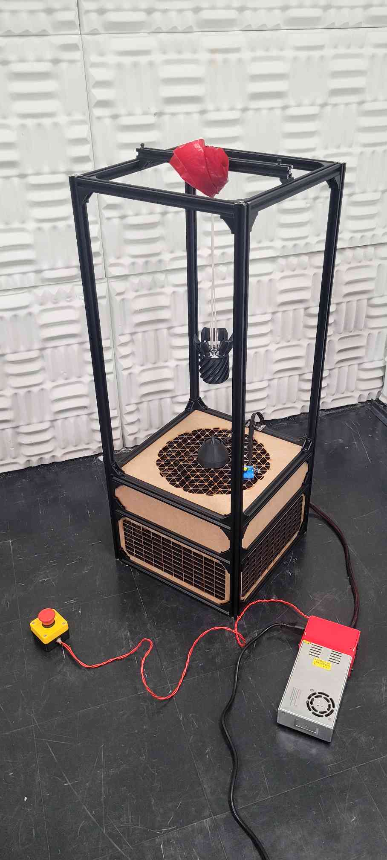
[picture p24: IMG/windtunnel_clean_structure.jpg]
Wind Tunnel Structure
  
</div>

We are using a servo motor tester as our speed control (it works with servos and brushless motors) and we check the airspeed with an anemometer.

  The device is powered by an 12V, 30A powersupply cased in a PLA box. Even if we are not using the motor at their full power it is enough to produce a 60km/h wind wich is more than our cansat is supposed to reach before deployment.

<div align="center">
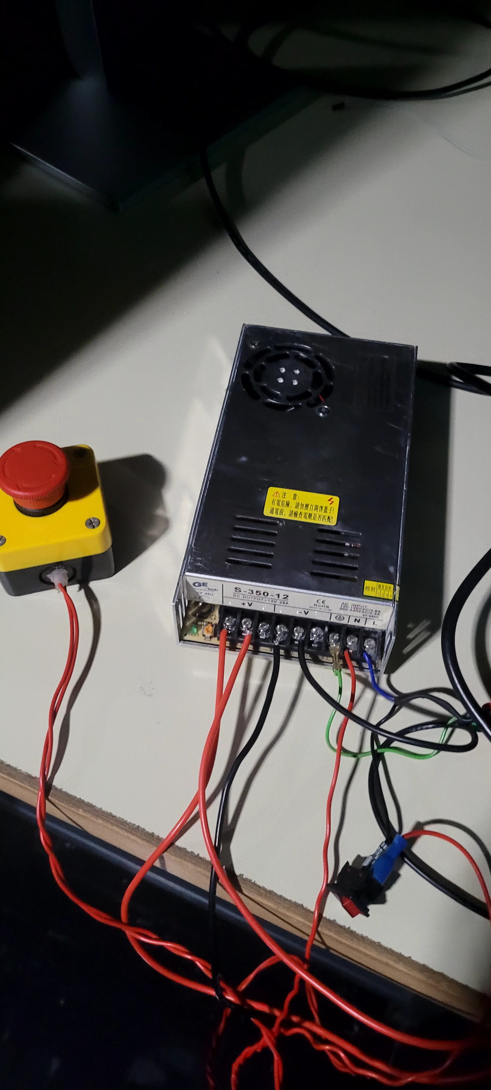
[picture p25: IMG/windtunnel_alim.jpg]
Wind Tunnel Power Supply
  
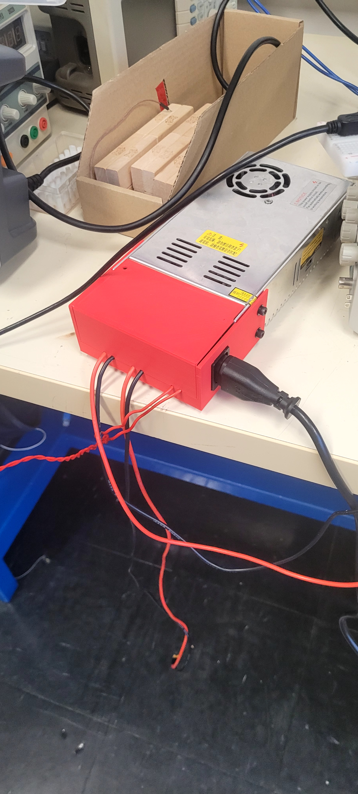
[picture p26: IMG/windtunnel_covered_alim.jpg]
Covered Power Supply
  
</div>

A one fan test :

<div align="center">
  One blade test
</div>

The motor has been covered with an aerospiked inspired nozzle in an attempt to preserve some of the air going around it:
<div align="center">
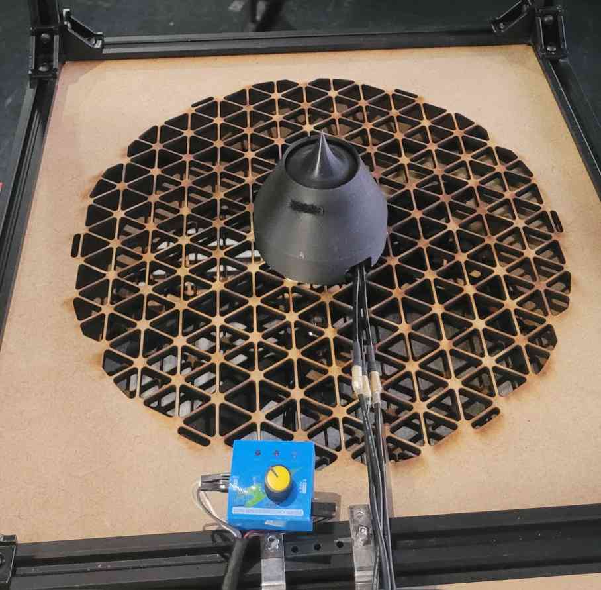
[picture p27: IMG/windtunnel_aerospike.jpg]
aerospkie cover
  
</div>

#### Precautions before use :
To use  the wind tunnel you must check that the propellers are clear and that nothing could get sucked in, then you must plug the power supply and turn it on (also check if the emergency button is not triggered). The knob of the servo tester should be set to 0, once the ESC made 3 bips the wind tunnel is armed and ready to be operated.

### ✈️ Drone

We did some early mechanical field test with a heavy duty drone that a professor kindly allowed us to use, but we plan on build our own to make more tests.

Here is the drop mechanism :
<div align="center">
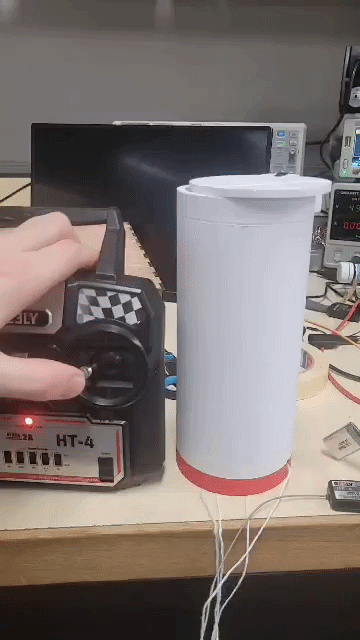
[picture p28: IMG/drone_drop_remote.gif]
Drone remote test
  
</div>

## 📚 Resources and useful links

### 👾 Used software 

- UCenter 2 - GNSS
- Lightware Studio - LIDAR
- STM32CubeIDE V.1.19.0 - STM32
- KiCAD - PCB Design
- OnShape - 3D modeling

### 🔗 Links 

- [Previous ENSEA CanSat GitHub](https://github.com/mathieupommery/CANSAT_ARES_ENSEA)
- [Onshape Folder](https://cad.onshape.com/documents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)
- [Kirigami inspierd parachute](https://www.nature.com/articles/s41586-025-09515-9#Fig1)
- [FreeRTOS Guide](https://www.youtube.com/watch?v=OPrcpbKNSjU) 
---

###  🚀 Future plans
The next steps will be :

- Improve the deployment reliability
- Finish the SD card code
- Prepare more field tests with a drone

From the current state of progress we expect to end the project in time with all of the missions.

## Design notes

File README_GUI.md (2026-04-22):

# 🛰️ Satellite Telemetry Monitor - LoRa Edition

**A high-performance real-time GUI application for monitoring and visualizing telemetry data from CubeSat/small satellites via LoRa communication on Raspberry Pi 5.**

      

---

## 📋 Table of Contents
1. [System Overview](#system-overview)
2. [Features](#features)
3. [Hardware Components](#hardware-components)
4. [Telemetry Protocol](#telemetry-protocol)
5. [Project Structure](#project-structure)
6. [Installation](#installation)
7. [Usage](#usage)
8. [Transmitter (STM32)](#transmitter-stm32)
9. [Receiver GUI (Raspberry Pi)](#receiver-gui-raspberry-pi)
10. [Data Analysis Tools](#data-analysis-tools)
11. [Signal Processing Tutorials](#signal-processing-tutorials)
12. [LIDAR Point Cloud Processing](#lidar-point-cloud-processing)
13. [Troubleshooting](#troubleshooting)
14. [Known Issues & Bug Fixes](#known-issues--bug-fixes)

---

## 🎯 System Overview

Complete satellite telemetry system with:
- **Real-time LoRa telemetry** at 869.53 MHz
- **High-speed LIDAR logging** (50 Hz) for 3D point cloud generation
- **Full sensor fusion** (IMU, GPS, Barometer, LIDAR)
- **Real-time GUI visualization** with 3D satellite model and map
- **Comprehensive post-flight analysis** suite
- **Signal processing tutorials** for educational purposes

### System Architecture

```
┌─────────────────────────────────────────────────────────────────┐
│                    SATELLITE (STM32G4)                          │
├─────────────────────────────────────────────────────────────────┤
│  Sensors:                                                       │
│    • ICM-20948 IMU (accel, gyro, mag)                           │
│    • BMP581 Barometer (altitude, temp)                          │
│    • GNSS (GPS position)                                        │
│    • LightWare SF20 LIDAR (distance)                            │
│    • Battery voltage (ADC)                                      │
│                                                                 │
│  Communication:                                                 │
│    • LoRa SX1276 @ 869.53 MHz → Ground Station                  │
│                                                                 │
│  Storage:                                                       │
│    • SD Card (NOT IMPLEMENTED YET)                              │
│      - LIDAR.CSV (high-speed, 50 Hz)                            │
│      - TELEM.CSV (full telemetry, 2 Hz)                         │
└─────────────────────────────────────────────────────────────────┘
                              ↓ LoRa
┌─────────────────────────────────────────────────────────────────┐
│              GROUND STATION (Raspberry Pi 5)                    │
├─────────────────────────────────────────────────────────────────┤
│  Hardware:                                                      │
│    • LoRa SX1276 receiver @ 869.53 MHz                          │
│                                                                 │
│  Real-Time GUI Software:                                        │
│    • main.py - Application launcher                             │
│    • gui_main_window.py - Main telemetry window                 │
│    • data_plotter.py - Real-time plots (3 graphs)               │
│    • satellite_3d.py - 3D STL model visualization               │
│    • map_view.py - Interactive OSM tile map                     │
│    • lora_data_handler.py - LoRa reception                      │
│    • Saves flight.csv with all data                             │
└─────────────────────────────────────────────────────────────────┘
                              ↓
┌─────────────────────────────────────────────────────────────────┐
│                POST-FLIGHT ANALYSIS SUITE                       │
├─────────────────────────────────────────────────────────────────┤
│  Basic Analysis:                                                │
│    • analyze_telemetry.py - Comprehensive flight report         │
│                                                                 │
│  Advanced Analysis:                                             │
│    • advanced_analysis.py - 6-panel automated analysis          │
│    • advanced_features.py - Physics-based deep analysis         │
│                                                                 │
│  Signal Processing:                                             │
│    • signal_processing_tutorial.py - Educational package        │
│    • Generates 4 Octave tutorials + Python examples             │
│                                                                 │
│  Point Cloud:                                                   │
│    • merge_point_cloud.py - LIDAR + GPS fusion                  │
│    • generate_synthetic_data.py - Test data generator           │
│    • Generates 3D terrain map                                   │
└─────────────────────────────────────────────────────────────────┘
```

---

## ✨ Features

### Real-Time Ground Station GUI:
- **Real-time Data Plotting**: Visualizes vertical speed, temperature, and altitude data in real-time
- **3D Satellite Visualization**: Shows your custom STL satellite model that rotates based on IMU data
- **2D Map Tracking**: Fast OSM tile map — tiles fetched once, position updates are instant
- **LoRa Communication**: Direct radio reception using SX127x LoRa module on Raspberry Pi 5
- **Resizable Layout**: Adjustable splitters to customize view sizes
- **Flight Phase Indicators**: Visual flags for calibration, drop, parachute deployment, and landing
- **Battery Monitoring**: Real-time battery percentage with 12-sample moving average smoothing
- **GPS Satellite Count**: Color-coded display of GPS fix quality

### Post-Flight Analysis:
- **Comprehensive Flight Reports**: 18-panel plots with statistics
- **Advanced Physics Analysis**: Drag coefficient, energy analysis, rotation detection
- **Signal Processing Education**: Low-pass filtering, FFT analysis, Kalman filtering
- **3D Point Cloud Generation**: LIDAR + GPS fusion for terrain mapping
- **Google Earth Export**: KML files for 3D flight visualization

---

## 🔧 Hardware Components

### Transmitter (Satellite)
| Component | Model | Interface | Purpose |
|---|---|---|---|
| MCU | STM32G431 | - | Main controller |
| IMU | ICM-20948 | I2C3 | Orientation, acceleration |
| Barometer | BMP581 | I2C1 | Altitude, temperature |
| GPS | Generic GNSS | UART1 | Position, time |
| LIDAR | LightWare SF20/LW20 | UART3 | Distance to ground |
| LoRa | SX1276 | SPI2 | Telemetry transmission |
| Battery Monitor | - | ADC1 | Voltage monitoring |
| SD Card | - | SPI (NOT IMPL.) | Data logging |

### Receiver (Ground Station)
| Component | Model | Interface | Purpose |
|---|---|---|---|
| Computer | Raspberry Pi 5 | - | Data reception & visualization |
| LoRa | SX1276 | SPI | Telemetry reception |
| Display | HDMI Monitor | - | GUI display |

**LoRa Hardware Connections (Raspberry Pi 5):**
- VCC → 3.3V / GND → GND
- MISO → GPIO 9 / MOSI → GPIO 10 / SCK → GPIO 11
- NSS/CS → GPIO 8 / RESET → GPIO 21
- DIO0 → GPIO 22 / DIO1 → GPIO 23 / DIO2 → GPIO 24

---

## 📡 Telemetry Protocol

### Protocol Version: **v2.4** (17-field)

### Packet Types

#### 1. Calibration Packet (sent once at startup)
```
CAL,<calibration_duration_ms>,<timestamp_ms>\r\n
```

**Example:**
```
CAL,3245,3245\r\n
```

**Fields:**
- `CAL` - Packet identifier
- `calibration_duration_ms` - Time taken to calibrate sensors (ms)
- `timestamp_ms` - STM32 timestamp when calibration completed (ms)

---

#### 2. Telemetry Packet (sent continuously during flight)
```
accel_x,accel_y,accel_z,gyro_x,gyro_y,gyro_z,roll,pitch,yaw,
temperature,altitude,latitude,longitude,satellites,flags,timestamp_ms,battery_voltage\r\n
```

**Example:**
```
0.12,0.15,9.81,1.2,0.5,0.3,5.2,2.1,45.3,22.5,385.2,48.8566,2.3522,8,3,4500,7.54\r\n
```

**17 Fields:**

| # | Field | Unit | Description |
|---|---|---|---|
| 1 | accel_x | m/s² | X-axis acceleration |
| 2 | accel_y | m/s² | Y-axis acceleration |
| 3 | accel_z | m/s² | Z-axis acceleration |
| 4 | gyro_x | °/s | X-axis rotation rate |
| 5 | gyro_y | °/s | Y-axis rotation rate |
| 6 | gyro_z | °/s | Z-axis rotation rate |
| 7 | roll | ° | Roll angle |
| 8 | pitch | ° | Pitch angle |
| 9 | yaw | ° | Yaw angle (heading) |
| 10 | temperature | °C | Barometer temperature |
| 11 | altitude | m | Altitude above sea level |
| 12 | latitude | ° | GPS latitude |
| 13 | longitude | ° | GPS longitude |
| 14 | satellites | count | GPS satellites locked |
| 15 | flags | bitmask | Flight phase flags |
| 16 | timestamp_ms | ms | STM32 timestamp |
| 17 | battery_voltage | V | Battery voltage |

**Note:** `vertical_speed` is **NOT transmitted**. The receiver calculates it from consecutive altitude readings:
```python
vertical_speed = (altitude_now - altitude_prev) / (time_now - time_prev)
```

---

### Flight Phase Flags (Bitmask)

| Bit | Value | Flag | Phase |
|-----|---|---|---|
| 0 | 0x01 | GO_FOR_LAUNCH | Ready for launch |
| 1 | 0x02 | ASCENSION | Ascending |
| 2 | 0x04 | DROP | Dropping/falling |
| 3 | 0x08 | RECOVERY | Recovery/landed |

**Examples:**
- `flags = 0` (0b0000) → Calibrating
- `flags = 1` (0b0001) → Ready for launch
- `flags = 3` (0b0011) → Ready + Ascending
- `flags = 7` (0b0111) → Ready + Ascending + Dropping
- `flags = 15` (0b1111) → All phases (recovered)

---

### LoRa Configuration

| Parameter | Value | Notes |
|---|---|---|
| Frequency | 869.53 MHz | EU ISM band |
| Spreading Factor | SF7 | Good range/data rate balance |
| Bandwidth | 125 kHz | Standard BW |
| Coding Rate | CR4/8 | Maximum error correction |
| Sync Word | 0x12 | Private network |
| TX Power | +17 dBm | Maximum allowed |
| Preamble | 8 symbols | Standard |

**Link Budget:**
- **Range:** ~5-10 km (line of sight)
- **Data Rate:** ~980 bps
- **Packet Size:** ~140 bytes
- **Air Time:** ~1.2 seconds per packet

---

## 📁 Project Structure

```
satellite_telemetry/
│
├── 📄 main.py                    # Application entry point
│   └── Launches GUI, handles venv path prioritization
│
├── 🖼️ gui_main_window.py         # Main telemetry display window (v2.4)
│   └── Integrates 3D view, map, plots; manages LoRa receiver lifecycle
│   └── Flag mapping: GO_FOR_LAUNCH, ASCENSION, DROP, RECOVERY
│
├── 📡 lora_data_handler.py       # LoRa receiver integration (v2.4)
│   └── SX127x hardware interface, CSV parsing (17 fields)
│   └── Battery voltage + GPS satellite count parsing
│   └── Labeled console output with emojis
│
├── 📊 data_plotter.py            # Real-time sensor data plotting (v2.4)
│   └── Optimized PyQtGraph plots with numpy circular buffers
│   └── Altitude-based vertical speed (no accelerometer drift!)
│   └── Battery percentage with 12-sample moving average smoothing
│   └── GPS satellite count display with color coding
│
├── 🛰️ satellite_3d.py            # 3D satellite model visualization
│   └── STL loader with optimized OpenGL rendering and rotation
│
├── 🗺️ map_view.py                # Interactive map widget
│   └── OSM tile-based map with async loading, zoom 18 detail
│
├── 📦 requirements.txt           # Python dependencies
│   └── PyQt5, PyQtGraph, NumPy, PyOpenGL, numpy-stl, etc.
│
├── 🎨 Corps.stl                  # Satellite 3D model (user-provided)
│   └── Custom STL file for your specific satellite design
│
├── 📖 README_GUI.md                  # This file
│   └── Complete documentation and usage guide
│
├── 📂 SX127x/                    # LoRa library (external dependency)
│   ├── __init__.py
│   ├── LoRa.py                   # Base LoRa class
│   ├── constants.py              # LoRa register constants
│   ├── board_config.py           # Raspberry Pi GPIO configuration
│   └── ...
│
├── 📂 Cansat_V1/               # STM32 firmware
│   └── Core/
│       ├── Src/
│       │   ├── main.c           # Main application
│       │   ├── bmp581.c         # Barometer driver
│       │   ├── imu.c            # IMU driver
│       │   ├── sx1276.c         # LoRa driver
│       │   ├── gnss_reader.c    # GPS parser
│       │   ├── lidar.c          # LIDAR driver
│       │   └── cansat_core.c    # Core definitions
│       └── Inc/
│           ├── main.h
│           ├── bmp581.h          # Barometer driver
│           ├── imu.h             # IMU driver
│           ├── sx1276.h          # LoRa driver
│           ├── gnss_reader.h     # GPS parser
│           ├── lidar.h           # LIDAR driver
│           └── cansat_core.h     # Core definitions
│   
│
└── 📂 Analysis_Tools/            # Post-flight analysis
    ├── Basic/
    │   └── analyze_telemetry.py     # Comprehensive report
    ├── Advanced/
    │   ├── advanced_analysis.py     # Automated suite
    │   └── advanced_features.py     # Physics-based analysis
    ├── Signal_Processing/
    │   └── signal_processing_tutorial.py  # Educational package
    └── Point_Cloud/
        ├── generate_synthetic_data.py     # Test data generator
        └── merge_point_cloud.py           # LIDAR + GPS fusion
```

### File Descriptions

| File | Lines | Purpose | Key Features |
|---|---|---|---|
| `main.py` | ~50 | Entry point | venv path fix, error handling |
| `gui_main_window.py` | ~220 | Main window | 4-panel layout, resource cleanup |
| `lora_data_handler.py` | ~180 | LoRa interface | SX127x config, CSV parsing, signals |
| `data_plotter.py` | ~280 | Data plots | Numpy buffers, 3 plots, flight flags |
| `satellite_3d.py` | ~240 | 3D rendering | STL loading, rotation, OpenGL |
| `map_view.py` | ~320 | Map display | Tile fetching, zoom 18, Y-axis inversion |

---

## 🚀 Installation

### Prerequisites

- **Raspberry Pi 5** with Raspberry Pi OS
- **SX127x LoRa module** connected to Raspberry Pi (SPI interface)
- Python 3.7 or higher
- Internet connection (for OSM map tiles on first load)

### Hardware Setup

1. **Connect LoRa Module to Raspberry Pi 5**:
   - VCC → 3.3V / GND → GND
   - MISO → GPIO 9 / MOSI → GPIO 10 / SCK → GPIO 11
   - NSS/CS → GPIO 8 / RESET → GPIO 21
   - DIO0 → GPIO 22 / DIO1 → GPIO 23 / DIO2 → GPIO 24

2. **Enable SPI**:
   ```bash
   sudo raspi-config  # Interface Options → SPI → Enable
   sudo reboot
   ```

### Software Setup

```bash
sudo apt-get update
sudo apt-get install python3-pyqt5 python3-spidev
pip install -r requirements.txt
```

> **Note**: `python3-pyqt5.qtwebengine` is NOT needed — QtWebEngine has been removed entirely.

---

## 🎮 Usage

### Running the Real-Time GUI

```bash
python main.py
# or with sudo for GPIO access:
sudo python main.py
```

### CSV Data Format (Receiver Output)

```csv
accel_x,accel_y,accel_z,gyro_x,gyro_y,gyro_z,roll,pitch,yaw,temperature,altitude,latitude,longitude,satellites,flags_raw,timestamp_ms,battery_voltage,rssi,snr
```

**Exported to:** `flight.csv` (automatically saved during reception)

### Interface Overview

**Top Left**: 3D STL model rotating with roll/pitch/yaw.

**Bottom Left**: OSM tile map (zoom 15, 5×5 tile grid). Tiles are fetched once at startup using 8 parallel threads and cached in memory. Position updates are instant — they only move PyQtGraph scatter/line overlay items with no tile work involved. The grid reloads only if the satellite leaves the current tile boundary. Blue polyline path + red dots per point.

**Right**: Vertical speed, temperature, altitude plots + flight phase flags.

**Bottom**: Stop/Clear buttons, LoRa status indicator.

---

## 🖥️ Transmitter (STM32)

### Current Implementation Status

| Feature | Status | Notes |
|---|---|---|
| IMU Reading | ✅ Implemented | ICM-20948 via I2C3 |
| Barometer Reading | ✅ Implemented | BMP581 via I2C1 |
| GPS Reading | ✅ Implemented | UART1 parsing |
| LIDAR Reading | ✅ Implemented | LightWare SF20 via UART3 |
| Battery Monitoring | ✅ Implemented | ADC1 with voltage divider |
| LoRa Transmission | ✅ Implemented | SX1276 at 869.53 MHz |
| Flight State Machine | ✅ Implemented | 5 states + transitions |
| SD Card Logging | ❌ **NOT IMPLEMENTED** | Ready for integration |

### Main Application Features

**main.c** includes:

#### RTOS Tasks (FreeRTOS)

1. **TaskFSM** - Flight State Machine
   - Priority: Normal
   - Stack: 1KB
   - Controls: State transitions, thresholds
   
2. **TaskSensors** - Sensor Data Acquisition
   - Priority: High (sensor reading critical)
   - Stack: 2KB
   - Handles: IMU, Baro, GPS, LIDAR events
   
3. **TaskSDCard** - Data Logging
   - Priority: Low
   - Stack: 1KB
   - Status: **EMPTY (NOT IMPLEMENTED)**
   - Planned: Dual-file logging (LIDAR.CSV + TELEM.CSV)
   
4. **TaskLoRa** - Radio Transmission
   - Priority: Low
   - Stack: 2KB
   - Handles: LoRa packet transmission

#### Queues

```c
QueueHandle_t qLoRa;          // Telemetry packets to transmit
QueueHandle_t qSensorEvents;  // Sensor event notifications
QueueHandle_t qSDCard;        // NOT USED (SD card not implemented)
```

#### Flight State Machine

```
CALIBRATING (0)
    ↓ (sensors stable)
READY (1) - GO_FOR_LAUNCH
    ↓ (altitude > 400m OR LIDAR < 2m)
ASCENSION (2)
    ↓ (LIDAR > 25m)
DROP (3)
    ↓ (stable on ground)
RECOVERY (4)
```

**Thresholds:**
```c
#define THRESH_ALTITUDE_LAUNCH_M     400.0f  // Launch altitude
#define THRESH_LIDAR_IN_BOX_M        2.0f    // LIDAR in box threshold
#define THRESH_LIDAR_DEPLOYED_M      25.0f   // Deployment threshold
```

### Battery Monitoring

**Circuit:**
```
Battery (7.4V) → R1 (20kΩ) → ADC1 ← R2 (10kΩ) → GND
```

**Voltage Divider Ratio:** 3.0× (accounts for 10kΩ/(20kΩ+10kΩ))

**ADC Reading:**
```c
HAL_ADC_Start(&hadc1);
if (HAL_ADC_PollForConversion(&hadc1, 10) == HAL_OK) {
    uint32_t raw_adc = HAL_ADC_GetValue(&hadc1);
    vbat = ((float)raw_adc / 4095.0f) * 3.3f * 3.0f * 1.025f;
    // 1.025 is calibration factor
}
HAL_ADC_Stop(&hadc1);
```

### SD Card Logging (Future Implementation)

**Planned Dual-File System:**

#### File 1: LIDAR.CSV (High-Speed, ~50 Hz)
```csv
timestamp_ms,distance_m,roll,pitch,yaw,latitude,longitude,altitude,flags
3501,12.34,5.2,2.1,45.3,48.8566,2.3522,385.2,3
3502,12.35,5.2,2.1,45.3,48.8566,2.3522,385.2,3
...
```

#### File 2: TELEM.CSV (Full Telemetry, ~2 Hz)
```csv
timestamp_ms,accel_x,accel_y,accel_z,gyro_x,gyro_y,gyro_z,roll,pitch,yaw,temperature,altitude,latitude,longitude,satellites,flags_raw,battery_voltage
3500,0.12,0.15,9.81,1.2,0.5,0.3,5.2,2.1,45.3,22.5,385.2,48.8566,2.3522,8,3,7.54
...
```

**Benefits:**
- No wasted space (no zeros)
- LIDAR at full rate
- Easy post-processing
- Small file sizes (~225 KB per 60s flight)

**See:** `main_with_lidar_logging.c` for implementation template

---

## 📻 Receiver GUI (Raspberry Pi)

### Software Components

#### 1. main.py
**Application entry point**

**Features:**
- venv path prioritization (fixes PyQtGraph version conflicts)
- Error handling and graceful shutdown
- Resource cleanup on exit

**Run:**
```bash
python main.py
```

---

#### 2. gui_main_window.py
**Main telemetry display window (v2.4)**

**Features:**
- 4-panel resizable layout
- Integrates 3D satellite view, map, and plots
- LoRa receiver lifecycle management
- Flight phase flag mapping
- CSV data export
- Resource cleanup on close

**Layout:**
```
┌─────────────────────────────────────┐
│  3D Satellite  │  Plots + Flags     │
│  (STL model)   │  (v_speed, temp,   │
│                │   altitude)        │
├─────────────────────────────────────┤
│  Map View      │  Controls          │
│  (OSM tiles)   │  (Stop/Clear/      │
│                │   Status)          │
└─────────────────────────────────────┘
```

---

#### 3. lora_data_handler.py
**LoRa receiver integration (v2.4)**

**Features:**
- SX127x hardware interface
- Packet type detection (CAL vs telemetry)
- 17-field CSV parsing
- Battery voltage monitoring
- GPS satellite count tracking
- RSSI/SNR monitoring
- Qt signal emission for GUI
- Labeled console output with emojis

**Configuration:**
- Frequency: 869.53 MHz
- Spreading Factor: SF7
- Bandwidth: 125 kHz
- Coding Rate: CR4/8
- Sync Word: 0x12

**Usage:**
```python
from lora_data_handler import LoRaDataReceiver

receiver = LoRaDataReceiver(verbose=True)
receiver.data_received.connect(on_data_callback)
receiver.configure_and_start()
```

---

#### 4. data_plotter.py
**Real-time sensor data plotting (v2.4)**

**Features:**
- Optimized PyQtGraph plots with numpy circular buffers (10,000 points)
- 3 real-time plots:
  1. **Vertical Speed** - Calculated from altitude deltas (m/s)
  2. **Temperature** - Barometer temperature (°C)
  3. **Altitude** - Above sea level (m)
- Flight phase color-coded backgrounds:
  - Gray: CALIBRATION
  - Blue: GO_FOR_LAUNCH
  - Green: ASCENSION
  - Red: DROP
  - Orange: RECOVERY
- Battery percentage with 12-sample moving average smoothing
- GPS satellite count display with color coding
- Auto-scaling axes
- Grid lines for readability

**Performance:**
- Update rate: Real-time (as packets arrive)
- Buffer size: 10,000 points
- Circular buffer prevents memory overflow

---

#### 5. satellite_3d.py
**3D satellite model visualization**

**Features:**
- STL file loader (reads `Corps.stl`)
- Optimized OpenGL rendering
- Real-time rotation based on IMU data:
  - Roll (X-axis)
  - Pitch (Y-axis)
  - Yaw (Z-axis)
- Smooth rotation interpolation
- Lighting and shading
- Perspective camera

**Supported formats:**
- Binary STL
- ASCII STL

---

#### 6. map_view.py
**Interactive map widget with OSM tiles**

**Features:**
- OpenStreetMap tile-based map
- Async tile loading with ThreadPoolExecutor (8 workers)
- Zoom level 18 detail
- 7×7 tile grid (auto-expands as satellite moves)
- In-memory tile caching
- Real-time GPS tracking:
  - Blue polyline path
  - Red dots per position
  - Red marker at current position
- Instant position updates (no tile re-fetching)
- Y-axis inversion fix for correct tile rendering
- Lazy tile loading (only fetches when needed)

**Performance:**
- First load: ~2-3 seconds (25 tiles fetched)
- Position updates: <1ms (zero network work)
- Tile cache: Permanent for session

**Map Controls:**
- Auto-centering on satellite position
- Pan viewport on GPS update
- Grid reloads only when satellite leaves boundary

---

## 📊 Data Analysis Tools

### Quick Reference

| Tool | Purpose | Input | Output | Runtime |
|---|---|---|---|---|
| analyze_telemetry.py | Comprehensive flight report | flight.csv | 18 plots + stats | ~10s |
| advanced_analysis.py | Automated 6-panel analysis | flight.csv | 6 analyses + folder | ~15s |
| advanced_features.py | Physics-based deep dive | flight.csv | 5 advanced analyses | ~20s |
| signal_processing_tutorial.py | Educational package | flight.csv | Python + 4 Octave scripts | ~5s |
| merge_point_cloud.py | 3D point cloud generator | LIDAR.CSV + TELEM.CSV | 3D terrain map | ~30s |
| generate_synthetic_data.py | Test data generator | - | LIDAR.CSV + TELEM.CSV | ~2s |

---

### 1. analyze_telemetry.py

**Basic flight analysis with comprehensive reporting**

#### Features:
- ✅ 18 time-series plots (one per field)
- ✅ Flight phase color-coded backgrounds
- ✅ Automatic statistics calculation
- ✅ Text report generation
- ✅ Windows-compatible (UTF-8 encoding)

#### Usage:
```bash
python analyze_telemetry.py flight.csv output_folder/
```

#### Output:
```
output_folder/
├── all_fields_plot.png          # 18-panel comprehensive plot
└── flight_analysis_report.txt   # Statistics summary
```

---

### 2. advanced_analysis.py

**Automated comprehensive analysis suite**

#### Features:
- ✅ 6 different analyses run automatically
- ✅ All outputs to single folder
- ✅ Publication-ready plots
- ✅ KML export for Google Earth

#### Usage:
```bash
python advanced_analysis.py flight.csv
```

#### Output:
```
advanced_analysis_folder/
├── 1_rotation_analysis.png      # Gyroscope magnitude + tumbling detection
├── 2_gps_trajectory.png         # 2D map + displacement calculation
├── 3_signal_quality.png         # RSSI/SNR vs altitude correlation
├── 4_anomaly_detection.txt      # Gap detection, GPS jumps, sensor issues
├── 5_energy_analysis.png        # Kinetic/potential energy over time
└── 6_google_earth.kml           # Import to Google Earth
```

---

### 3. advanced_features.py

**Physics-based deep analysis**

#### Features:
- ✅ 5 advanced analyses
- ✅ Animated flight replay (GIF)
- ✅ 3D orientation visualization
- ✅ Drag coefficient calculation
- ✅ Parachute deployment detection
- ✅ Power consumption analysis

#### Usage:
```bash
python advanced_features.py flight.csv
```

---

## 🎓 Signal Processing Tutorials

### signal_processing_tutorial.py

**Educational package teaching signal processing with real flight data**

#### What it Creates:

```
signal_processing_output/
├── README.txt                          # Getting started guide
├── telemetry_data.mat                  # MATLAB/Octave format (21 fields)
├── python_filtering_demo.png           # Low-pass filter example
├── python_fft_demo.png                 # FFT analysis example
├── octave_tutorial_1_basics.m          # Loading & plotting
├── octave_tutorial_2_filtering.m       # Filter design
├── octave_tutorial_3_fft.m             # Frequency analysis
└── octave_tutorial_4_kalman.m          # Kalman filter
```

#### Usage:
```bash
python signal_processing_tutorial.py flight.csv
```

#### Key Concepts Taught:

**Low-Pass Filtering:**
- Why? Remove high-frequency noise (vibrations, ADC jitter)
- How? Keep signals below cutoff, attenuate above
- When? Temperature smoothing, GPS cleaning

**FFT Analysis:**
- Why? Reveal hidden patterns in data
- How? Decompose signal into frequency components
- When? Finding rotation rates, vibration frequencies

**Kalman Filtering:**
- Why? Optimal fusion of noisy measurements with physics model
- How? Predict using model, correct using measurements
- When? GPS smoothing, sensor fusion

---

## 🗺️ LIDAR Point Cloud Processing

### System Overview

Fuses GPS position with LIDAR distance measurements to create 3D terrain map.

**Physics:**
```
Ground_Point = Satellite_Position + (LIDAR_Distance × Direction_Vector)

Where:
  Satellite_Position = (latitude, longitude, altitude) from GPS
  Direction_Vector = calculated from (roll, pitch, yaw) using rotation matrices
  LIDAR_Distance = distance measurement from LIDAR sensor
```

---

### 1. generate_synthetic_data.py

**Creates realistic test data for development**

#### Usage:
```bash
python generate_synthetic_data.py
```

#### Output:
```
LIDAR.CSV       231 KB   3000 readings @ 50 Hz
TELEM.CSV       18 KB    120 packets @ 2 Hz
```

#### Scenario Simulated:
```
0-5s:    Calibration (ground, 400m altitude)
5-15s:   Go for launch (waiting)
15-35s:  Ascension to 500m (~5 m/s climb)
35-60s:  Drop with tumbling (terminal velocity ~15 m/s)
60s+:    Recovery/landing
```

---

### 2. merge_point_cloud.py

**Merges LIDAR + Telemetry into 3D point cloud**

#### Usage:
```bash
python merge_point_cloud.py LIDAR.CSV TELEM.CSV
```

#### Output:
```
point_cloud.csv                     # Full merged dataset
point_cloud_XYZ.txt                 # For CloudCompare import
point_cloud_visualization.png       # 6-panel plot
```

#### CloudCompare Workflow:

**1. Import Point Cloud:**
```
File → Open → point_cloud_XYZ.txt
Format: ASCII (space-separated)
Columns: X=longitude, Y=latitude, Z=altitude
```

**2. Colorize by Altitude:**
```
Edit → Colors → Height Ramp
Choose color scheme (e.g., terrain)
```

**3. Export:**
```
File → Save As
Formats: .las, .laz (LiDAR standard), .ply, .obj
```

---

## 🔧 Troubleshooting

### LoRa Module Not Detected
- Verify SPI: `lsmod | grep spi`
- Check GPIO connections
- Try: `sudo python main.py`

### Map tiles slow to appear on first load
- This is normal — 25 tiles are fetched on startup
- After that, updates are instant
- Subsequent runs reuse the in-memory cache for the session

### Invalid GPS coordinates
- Values outside lat [-90,90] / lon [-180,180] are rejected
- This is a transmitter calibration issue, not a software bug
- Check GPS antenna and sky view

### GPS: No lock
- Clear sky view required
- Wait 2-3 minutes for cold start
- Check antenna connected
- Verify UART baud rate: 9600 or 115200

### LIDAR: No data
- Check UART3 baud: 115200
- Stream mode enabled: `Lidar_RequestStream()`
- Use `Lidar_DirectDebug()` to verify

### Analysis: Script crashes
- Check Python dependencies installed
- Verify CSV file not corrupted
- Ensure correct column names
- Check for empty data

---

## 🐛 Known Issues & Bug Fixes

### Fix 1 — PyQtGraph `drawLines` TypeError (`main.py`)
**Symptom**: `TypeError: arguments did not match any overloaded call: drawLines(...)`

**Cause**: System pyqtgraph 0.13.1 being loaded instead of venv's 0.14.0.

**Fix**: `main.py` inserts the venv's site-packages at the front of `sys.path` before any imports.

---

### Fix 2 — QtWebEngine Chromium crash → removed entirely (`map_view.py`)
**Symptom**: `FATAL: page_allocator_internals_posix.h(169)] Check failed` / `Trace/breakpoint trap`

**Cause**: Chromium renderer incompatible with Raspberry Pi 5 ARM kernel memory allocator. No flag combination (`--no-sandbox`, `--disable-gpu`, `--single-process`) resolved it.

**Fix**: QtWebEngine removed entirely. Map reimplemented in PyQtGraph with urllib tile fetching.

---

### Fix 3 — Map too slow to update (`map_view.py`)
**Symptom**: Map position updates were visibly laggy.

**Cause**: Tiles were being fetched and composited on every `update_position()` call.

**Fix**: Tile loading and overlay updates are now fully decoupled:
- `_load_tiles()` runs once at startup in a `ThreadPoolExecutor` with 8 workers
- `update_position()` only calls `_redraw_overlays()` which moves PyQtGraph items — zero network or compositing work
- Tiles are cached in memory; the grid only reloads when the satellite leaves its boundary

---

### Fix 4 — Y-axis tile inversion (`map_view.py`)
**Symptom**: Map tiles displayed upside-down.

**Cause**: OSM uses TMS tile coordinates (Y increases southward), but PyQtGraph ImageItem expects Y increasing upward.

**Fix**: Apply Y-axis inversion when positioning ImageItems:
```python
tile_y_inverted = (2**zoom - 1) - tile_y
```

---

### Fix 5 — Map slow to rebuild on GPS update (`map_view.py`)
**Symptom**: Map was slow to respond to incoming GPS positions.

**Cause**: Previous implementation rebuilt a numpy canvas on every GPS update — re-blitting all visible tiles into a single array each time.

**Fix**: Tiles are now permanent `pg.ImageItem` objects placed once at fixed world coordinates and never moved or rebuilt. Each GPS update does only three O(1) `setData` calls (polyline, dots, marker) and a viewport pan — zero tile work. A 7×7 tile grid is pre-fetched asynchronously at startup and lazily expanded as the satellite moves.

---

## 📊 Performance Metrics

### System Performance

| Metric | Value | Notes |
|---|---|---|
| Telemetry Rate | ~2 Hz | Limited by LoRa air time |
| LIDAR Rate | ~50 Hz | (Future, on SD card) |
| LoRa Range | 5-10 km | Line of sight |
| Packet Loss | <5% | Typical in good conditions |
| Battery Life | ~2 hours | Depends on usage |
| SD Card Storage | ~4400 flights | 1 GB card, 60s flights |
| GUI Update Rate | Real-time | <50ms latency |
| Map Tile Load | ~2-3 seconds | First load only |
| Map Update | <1ms | After tiles loaded |

### File Sizes (60 second flight)

| File | Size | Samples | Rate |
|---|---|---|---|
| flight.csv (receiver) | ~15 KB | ~120 | 2 Hz |
| LIDAR.CSV (SD card) | ~231 KB | ~3000 | 50 Hz |
| TELEM.CSV (SD card) | ~18 KB | ~120 | 2 Hz |
| **Total per flight** | **~250 KB** | - | - |

---

## 📚 Additional Resources

### Python Dependencies
```bash
# Core dependencies
pip install numpy pandas matplotlib scipy

# For GUI (receiver)
pip install pyqt5 pyqtgraph pyopengl numpy-stl

# For LoRa (Raspberry Pi only)
pip install RPi.GPIO spidev
```

### Octave/MATLAB
```bash
# Install Octave (free, open-source)
sudo apt install octave
```

### CloudCompare
```
Download: https://www.danielgm.net/cc/
Free, open-source 3D point cloud processing
```

---

## 📝 Version History

### v2.4 (Current)
- ✅ 17-field telemetry protocol
- ✅ Battery voltage monitoring
- ✅ GPS satellite count display
- ✅ Optimized PyQtGraph plots
- ✅ Fast OSM tile map
- ✅ Complete analysis suite
- ✅ Signal processing tutorials
- ✅ Point cloud processing pipeline
- ❌ SD card logging (not yet implemented)

### v2.3
- ✅ LIDAR integration
- ✅ Flight phase flags

### v2.2
- ✅ GPS satellite count added
- ✅ Calibration packet

### v2.1
- ✅ Initial LoRa telemetry
- ✅ Basic sensor fusion
- ✅ FSM implementation

---

## ⚠️ Important Notes

**Current Limitations:**
- ❌ SD card logging **NOT IMPLEMENTED** in main.c
- ❌ TaskSDCard is empty (placeholder)
- ✅ All other features working

**Before Flight:**
- ✅ Test LoRa communication
- ✅ Verify GPS lock
- ✅ Check battery voltage
- ✅ Calibrate sensors
- ✅ Test real-time GUI
- ❌ Cannot log to SD card yet (future feature)

**Data Analysis:**
- ✅ All tools tested with synthetic data
- ✅ Point cloud pipeline validated
- ✅ CloudCompare export working
- ✅ Octave tutorials functional
- ✅ GUI tested on Raspberry Pi 5

---

## 🎯 Future Enhancements

**High Priority:**
1. ⬜ Implement SD card logging (dual-file system)
2. ⬜ Add real-time LIDAR visualization in GUI
3. ⬜ Implement data compression

**Medium Priority:**
4. ⬜ Add second GPS for redundancy
5. ⬜ Implement parachute deployment detection
6. ⬜ Add temperature compensation for sensors
7. ⬜ Export to Google Earth from GUI

**Low Priority:**
8. ⬜ Machine learning for anomaly detection
9. ⬜ Predictive landing zone calculation
10. ⬜ Real-time 3D point cloud streaming

---

## 📜 License

This project is provided as-is for educational and research purposes.

---

## 🎓 Educational Use

This system is designed for educational purposes and includes:
- Complete signal processing tutorials
- Physics-based analysis examples
- Octave/MATLAB learning materials
- Real-world sensor fusion examples
- Real-time visualization techniques

Perfect for:
- Engineering students
- CanSat competitions
- Rocketry projects
- Drone development
- Signal processing education
- GUI development learning

---

*Built with ❤️ for the Cansat*

---

**README.md Version:** 2.4.0  
**Last Updated:** 2025-04-22  
**System Status:** Operational (SD card pending)

---

**END OF DOCUMENTATION**

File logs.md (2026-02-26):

#  Session Logs

## Session 0 – *09/09/2025*
- **Project Definition**  
  - Discussed general project organization  
  - Missions not yet revealed  
- **Decisions**  
  - Study previous CanSat team's GitHub as reference  
  - Start designing our own motherboard  
  - Focus: modular design → adaptable to different peripherals  
- **Progress**  
  - Listed components and sensors to implement  
- **Goals for Next Session**  
  - Learn basics of required tools:  
    - Onshape  
    - FreeRTOS   
    - GitHub etiquette

## Session 1 – *15/09/2025*
- **Project Definition**  
  - Roles distribution
  - Missions not yet revealed  
- **Decisions**  
  - Study previous CanSat team's GitHub as reference  
  - Focus on testing the sensors while we wait for the rules
- **Progress**  
  - Ordered most of the sensors
  - Set deadlines
- **Goals for Next Session**  
  - Work on the test motherboard

## Session 2 – *23/09/2025*
- **Project Definition**  
  - Missions not yet revealed
- **Decisions**  
  - Reverse engineer previous team's code and implementation
- **Progress**  
  - Analyzed last year's code structure and libraries
  - Studied communication protocols and sensor integration
- **Goals for Next Session**  
  - Complete analysis of previous implementation
  - Prepare for mission announcement

## Session 3 – *30/09/2025*
- **Project Definition**  
  - **NEW: Mission requirements published**
- **Decisions**  
  - Finalize reverse engineering of previous codebase
  - Begin planning for new mission requirements
- **Progress**  
  - Completed analysis of libraries and implementation
  - Documented communication protocols from previous design
- **Goals for Next Session**  
  - Start GNSS receptor configuration
  - Adapt code structure to new missions

## Session 4 – *07/10/2025*
- **Project Definition**  
  - Mission requirements defined
- **Decisions**  
  - Focus on GNSS receptor implementation
- **Progress**  
  - Started GNSS module configuration
  - Tested basic positioning functionality
- **Goals for Next Session**  
  - Complete GNSS integration
  - Begin communication protocol development

## Session 5 – *14/10/2025*
- **Project Definition**  
  - Mission requirements defined
- **Decisions**  
  - Continue GNSS optimization
- **Progress**  
  - Advanced GNSS receptor implementation
  - Improved positioning accuracy and data parsing
- **Goals for Next Session**  
  - Finalize GNSS functionality
  - Begin sensor data integration

## Session 6 – *21/10/2025*
- **Project Definition**  
  - Second report completion and project planning
- **Decisions**  
  - Parallel development across all technical areas
  - Focus on integration testing
- **Progress**  
  - **Communications**: SX1276 module testing and investigation with ground station
  - **3D Design**: Prototype printing and parachute investigation
  - **Programming**: UBX message data extraction implementation
  - **Electronic Design**: LiDAR sensor investigation
- **Goals for Next Session**  
  - Continue module integration
  - Begin system-wide testing
  - Refine parachute design based on prototype results

## Session 7 – *28/10/2025*
- **Project Definition**  
  - Refining the architecture and completing the second status report.
  - Definition of primary (Atmospheric sounding) and secondary (Topo-mapping) missions.

- **Decisions**  
  - **Sensors**: Replacement of the accelerometer with the BNO055 (9-axis IMU) for better orientation data.
  - **Power**: Selection of a 9V Li-ion battery (600 mAh) for an estimated autonomy of 11 hours.
  - **MCU**: Confirmation of STM32L432KC as the main microcontroller.
- **Progress**  
  - **Electronic Design**: Schematic completed in KiCad; warnings cleared, but some errors remain.
  - **Station Sol**: Development of the Python GUI using Tkinter for real-time graphing and logging.
  - **Communications**: Testing GPS accuracy (latitude/longitude error analysis) and ground station reception.
  - **Parachute**: Research into drogue chute types and ballistics.
- **Goals for Next Session**  
  - Fix remaining schematic errors and prepare for routing.
  - Define specific team identity and branding.

## Session 8 – *04/11/2025*
- **Project Definition**  
  - Formalization of team identity and presentation to first-year students.

- **Decisions**  
  - **Team Name**: Adopted "Vortex" as the project name, referencing the spinning strategy.
  - **Mechanics**: Defined parachute diameters: 65cm for the main chute and 45cm for the second chute.
- **Progress**  
  - **Electronic Design**: Schematic fully completed without errors or warnings; ready for routing.
  - **Project Management**: Preparation of presentation materials for student recruitment.
- **Goals for Next Session**  
  - Create project logo and team assets.
  - Begin physical testing of communication modules at home.

## Session 9 – *11/11/2025*
- **Project Definition**  
  - Detailed task distribution among team members to parallelize workflow.

- **Decisions**  
  - Work Distribution: Amr (PCB Design), Ted (LoRa/Github), Juan Pablo (LoRa/Cameras), Abdel (Python mapping), Alexei (PCB/Flaps)
- **Progress**  
  - **Communications**: Retrieval of Nucleo boards and SX1276 modules for individual testing at home.
  - **Electronic Design**: Clarification of power supply modes (shorting PWR pin with E5V) for the Nucleo board.
  - **General**: Creation of the team logo.
- **Goals for Next Session**  
  - Select specific power inductors for the PCB.
  - Finalize sensor selection for the topography mission.

## Session 10 – *11/11/2025*
- **Project Definition**  
  - Preparation for the RCE (Rencontres des Clubs Espace) event in Paris.

- **Decisions**  
  - **Components**: Selection of Würth MAPI power inductors (shielded, high current).
  - **Sensors**: Selection of the Lightware LW20/C LiDAR/ToF sensor for the mapping mission.
- **Progress**  
  - **Events**: Logistics planning for the RCE event on November 22.
- **Goals for Next Session**  
  - Integrate RCE feedback into the project design.
  - Prepare the CANSAT 4 presentation.

## Session 11 – *25/11/2025*
- **Project Definition**  
  - Major design review following RCE feedback and submission of technical reports.

- **Decisions**  
  - **Routing Strategy**: Implementation of a 4-layer PCB (Signal, Ground, Power, Signal) with 9V, 5V, and 3.3V rails.
  - **Mechanics**: Validation of the spinning strategy using servo-controlled flaps.
  - **GPS Placement**: Moving GPS to the top of the CanSat based on RCE feedback.
- **Progress**  
  - **Electronic Design**: Completion of mainboard routing and design of a separate IHM (Interface Homme Machine) board.
  - **Communications**: Successful "Hello World" LoRa transmission and protocol definition.
  - **3D Design**: Modeling of the internal rack and aerodynamic flaps.
  - **Logistics**: Final component orders placed.
- **Goals for Next Session**  
  - Submit the "Dossier de définition".
  - Fix identified PCB connection errors.

  ## Session 12 – *02/12/2025*
- **Project Definition**  
  - Submission of the Definition Dossier defining team goals and preliminary designs.

- **Decisions**  
  - **Mechanics**: Focus shifted to advanced 3D modeling of the structure.

- **Progress**  
  - **Documentation**: "Dossier de définition" completed and sent.
  - **Electronic Design**: Identification of a critical routing mistake (GPS connected to Ven instead of LoRa) to be fixed in V2.
- **Goals for Next Session**  
  - Define specific PCB manufacturing rules.
  - Research handling protocols for sensitive sensors.

  ## Session 13 – *09/12/2025*
- **Project Definition**  
  - Refinement of hardware handling and manufacturing specifications.

- **Decisions**  
  - **Manufacturing**: Set IHM PCB track width to 0.5mm and vias to 0.6mm.
  - **Sensor Handling**: Strict protocol adopted for BMP581 (plastic tweezers only) due to fragility.

- **Progress**  
  - **Sensors**: Discovery of BNO055 PCB optimization guides and confirmation of temperature extraction from the BMP581.
  - **Station Sol**: Integration of battery status and temperature monitoring into the receiver logic.
- **Goals for Next Session**  
  - Solder and test the received V1 PCBs.
  - Present the Ground Station GUI.

    ## Session 14 – *16/12/2025*
- **Project Definition**  
  - Physical integration.

- **Decisions**  
  - **Data Flow**: Finalized architecture as GNSS > STM32 > SX1276 > Ground Station.

- **Progress**  
  - **Electronic Design**: Mainboard V1 received and soldered; IHM PCB completed.
  - **Station Sol**: Demonstration of the GUI with RSSI and sensor data integration.
  - **Sensors**: Waiting for specific connectors (DF52) for the LiDAR.
- **Goals for Next Session**  
  - Power testing of the PCB (LDO and Buck converters).
  - Perform wind tunnel testing for the mechanical structure.

    ## Session – *23/12/2025*
- **Project Definition**  
  - Critical hardware testing and validation phase during the break.

- **Decisions**  
  - **PCB V2**: Added correction of the first buck converter footprint to the V2 task list.
  - **Sensor Handling**: Strict protocol adopted for BMP581 (plastic tweezers only) due to fragility.

- **Progress**  
  - **Electronic Design**: Confirmed LDO outputs clean 3.3V and Buck converter outputs clean 5V.
  - **Mechanics**: Successful wind tunnel tests.
- **Goals for Next Session**  
  -  Resume project work after the exam period.

## Session 15 – *13/01/2026*
- **Project Definition**  
  - Work on tasks defined in the roadmap

- **Decisions**  
  - Organize the Github repository

- **Progress**  
  - **Main PCB**: Managed to light a led.
  
- **Goals for Next Session**  
  -  Station Sol 3D Modelling

## Session 16 – *20/01/2026*
- **Project Definition**  
  - Work on tasks defined in the roadmap

- **Decisions**  
  - Work on tasks defined in the roadmap

- **Progress**  
  - Wind tunnel : Testing the can's rotation and replacing the controller with an ESC device.
  - State Machine
  - Kalman's filter for the can's trajectory
  - Main PCB : V2, fixed previous issues
  - HMI PCB : Soldering and testing
  - Branding
  - Soldered connections for the IMU
  - Soldered connections to use the LoRa via the RaspBerry
- **Goals for Next Session**  
  -  Not defined

## Session 17 – *27/01/2026*
- **Project Definition**  
  - Work on tasks defined in the roadmap
  - Report 5

- **Decisions**  
  - Work on tasks defined in the roadmap

- **Progress**  
  - Successfully received a message by using the RaspBerry.
  - Minimum changes in LiDAR code.
  - Stickers
  - Can's internal structure
  - Discussing how to control the camera via PCB
  - Main PCB : V2, solved issue with powering the camera
  - Another PCB in the making (with an npn transistor) to link camera and main board
  - HMI PCB : Soldering 
  - FreeRTOS and FATFS for SD card
- **Goals for Next Session**  
  -  Not defined

## Session 18 – *03/02/2026*
- **Project Definition**  
  - Work on tasks defined in the roadmap

- **Decisions**  
  - Work on tasks defined in the roadmap

- **Progress**  
  - Improving the code of the LoRa.
  - Mainboard v2: Corrected camera circuitry and added test points.

  - Camera Interposer PCB: Finalized schematics and routing.

  - HMI PCB Testing: Investigating a 3.3V-to-GND short circuit occurring after LED soldering (potential causes: soldering bridge or button footprint issues).

  - Testing SD card
- **Goals for Next Session**  
  -  Not defined

## Session 19 – *10/02/2026*
- **Project Definition**  
  - Work on tasks defined in the roadmap

- **Decisions**  
  - Work on tasks defined in the roadmap

- **Progress**  
  -  New version of FSM 
  - Flow diagrams of the system V1
  - Beginning the Cansat V1 code
  - RCE2
  - Conception de parachute
  - Peaufinage de la V2
  - Tests LEDs pcb IHM
  - Calculs et dimensionnement du parachute

- **Goals for Next Session**  
  -  Not defined

## Session 20 – *17/02/2026*
- **Project Definition**  
  - Work on tasks defined in the roadmap
  - Report 6

- **Decisions**  
  - Work on tasks defined in the roadmap

- **Progress**  
  - Test du BNO055
  - Test du baromètre
  - Floquage
  - Recensement des valeurs de courants min, typ, max et peak de chaque élément du pcb (baromètre, imu etc)
  - Reflexion sur l'ajout de sécurité concernant le pcb mainboard (fusible, TVS, diode Schottky)

- **Goals for Next Session**  
  -  Not defined

## Session 21 – *10/03/2026*
- **Project Definition**  
  - Work on tasks defined in the roadmap

- **Decisions**  
  - Work on tasks defined in the roadmap

- **Progress**  
  - 

- **Goals for Next Session**  
  -  Not defined

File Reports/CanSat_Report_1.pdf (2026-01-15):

# CanSat

2025-2026

Alexeï DOUILLARD
Juan Pablo BARONA CIFUENTES Ted KOYAZANDE
Amr TAOUIS
Abdelmoughit HAJJI LAAMOURI

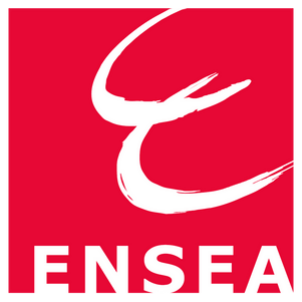
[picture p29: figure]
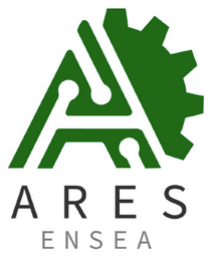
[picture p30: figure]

# 1. Introduction

# 2. Objectifs

# 3. Plannification

# Index

# 4. Etude du CanSat

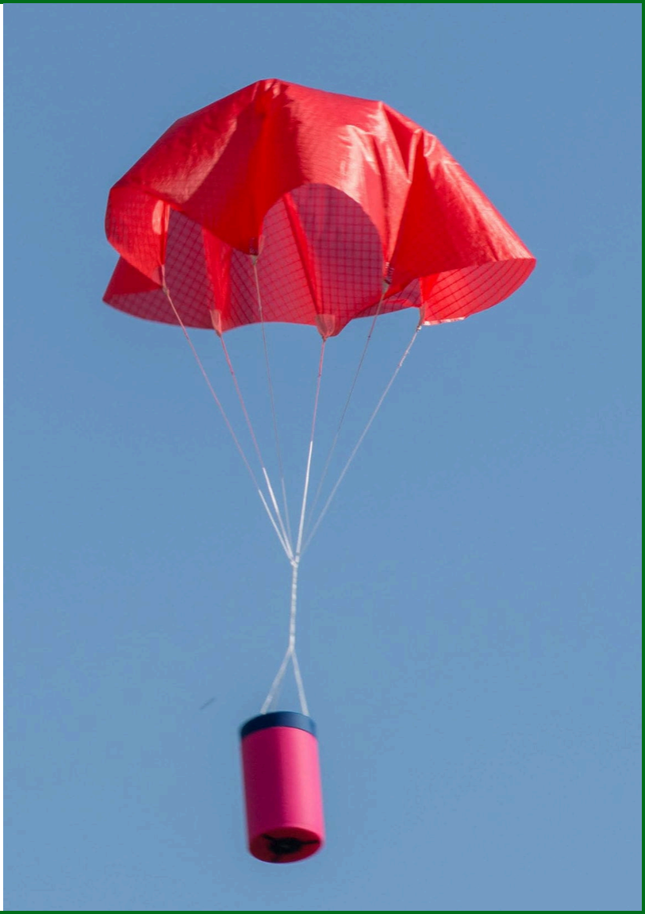
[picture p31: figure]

# Objectifs

Identifier et expliquer les principes fondamentaux de l'ingénierie aérospatiale pertinents pour la
mission | CANSAT, | notamment | la | détection
atmosphérique, la télémétrie radio, la balistique des parachutes et la gestion de l'énergie.

Concevoir et intégrer tous les sous-systèmes validés dans un satellite compact, qui réponde avec succès aux exigences de la mission principale et secondaire.

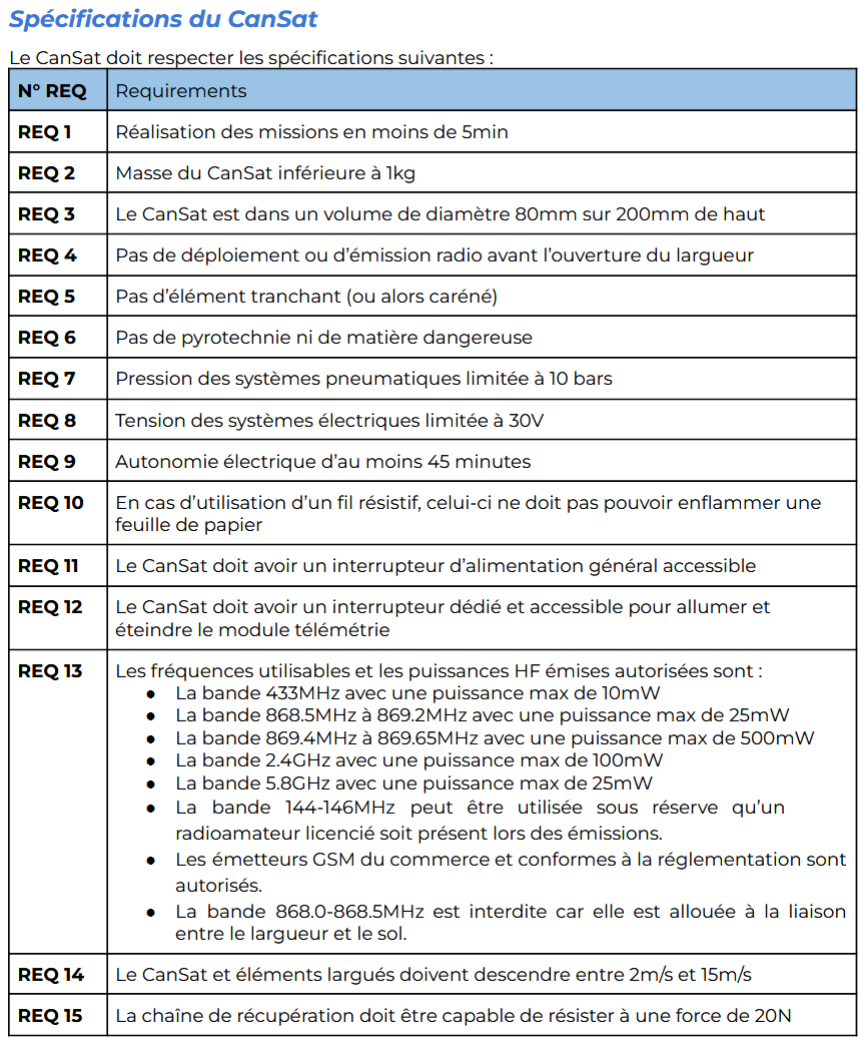
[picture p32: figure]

# Regles

# Regles

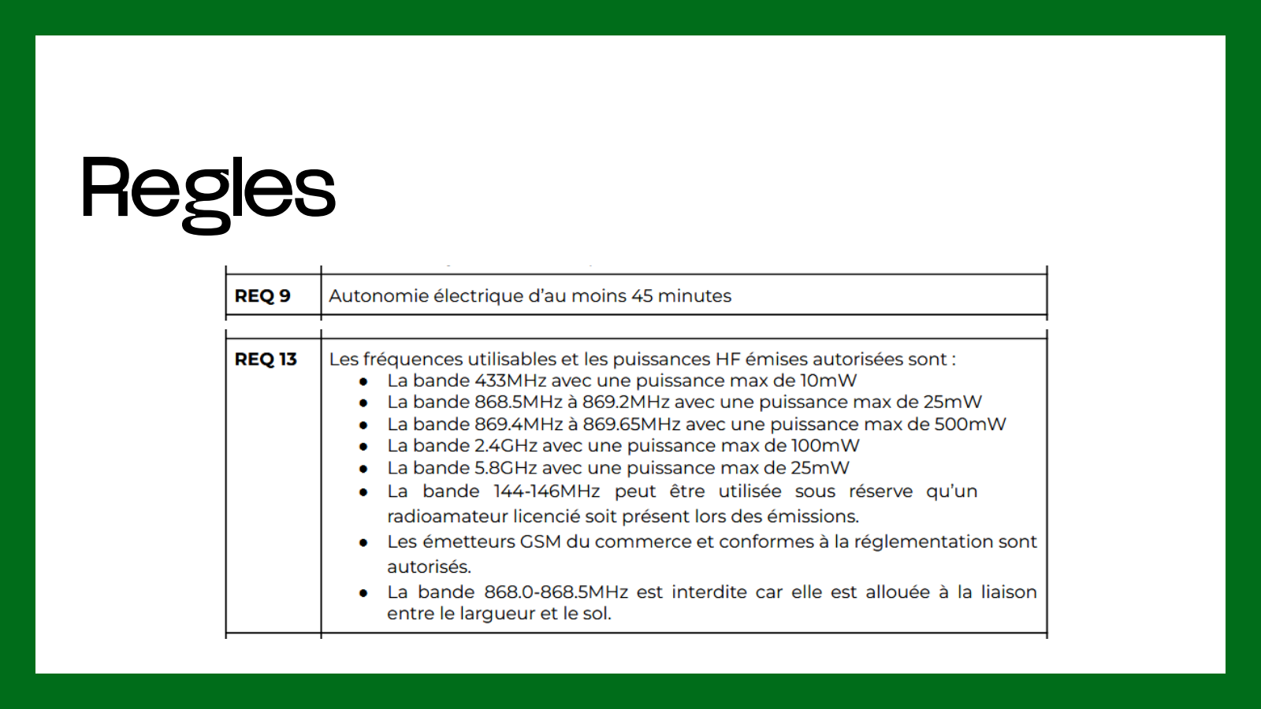
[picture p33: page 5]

# Plannification

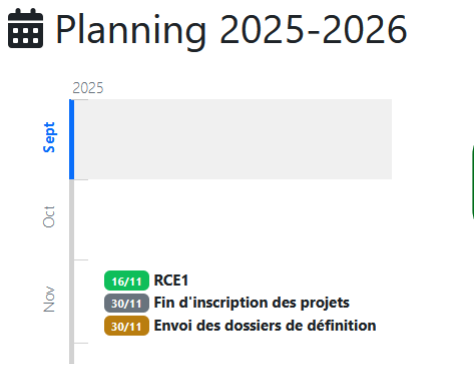
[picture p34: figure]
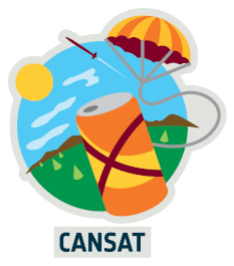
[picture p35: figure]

16

## Novembre

## Avant règlement : Prototypes

# Plannification

## Tests et itérations

## Après règlement : Adaptation et itérations

# 1er Etape 2me Etape 3me Etape

# Plannification

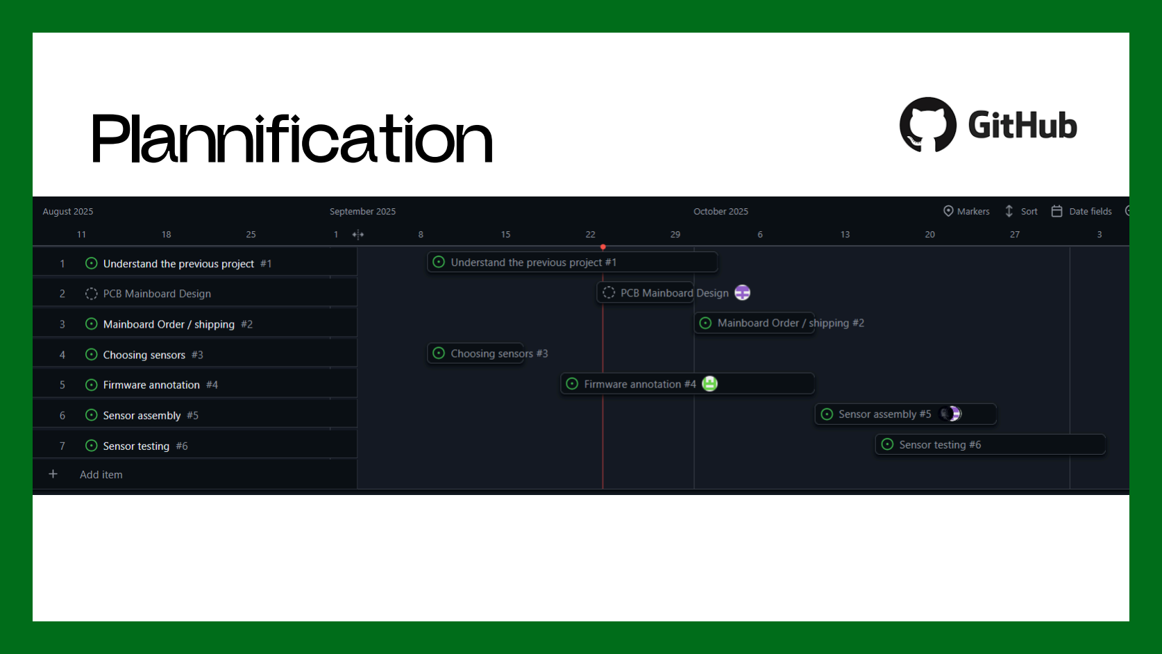
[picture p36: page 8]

# Plannification

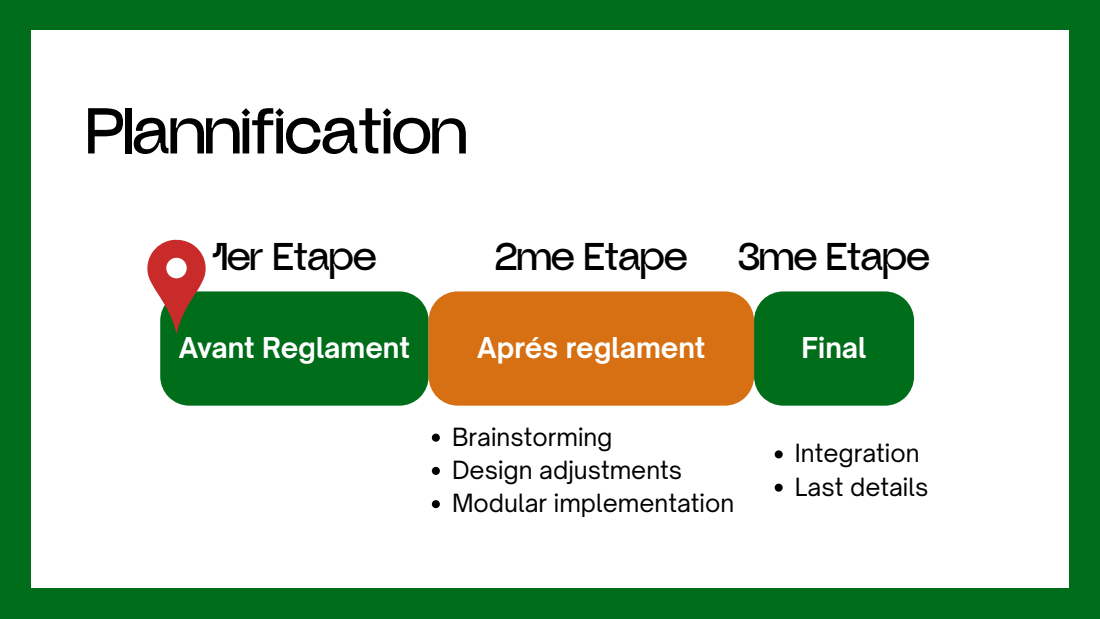
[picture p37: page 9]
Avant Reglament; Aprés reglament; Final; 1er Etape; 2me Etape 3me Etape; Brainstorming Design adjustments Modular implementation; Integration Last details

# Plannification

3d | Comms | station
Programming | Electronic Design

# Plannification

3d | Comms | station
Programming | Electronic Design
Alexeï | JUanPablo | TED
abdelmoughit | amr

3D

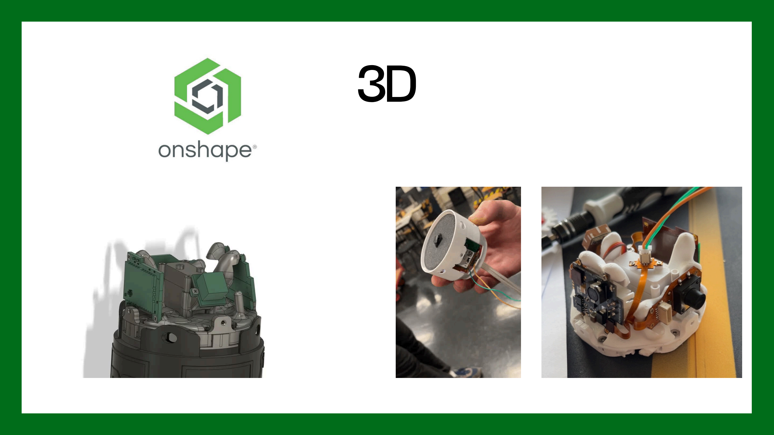
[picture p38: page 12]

# COMMS

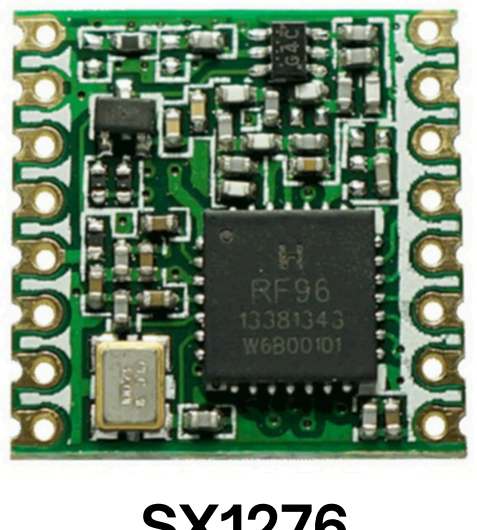
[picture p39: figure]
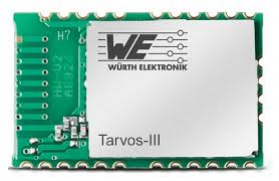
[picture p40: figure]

Tarvos-IIII | SX1276
| Cheaper More flexibility

## Problem with ack packet

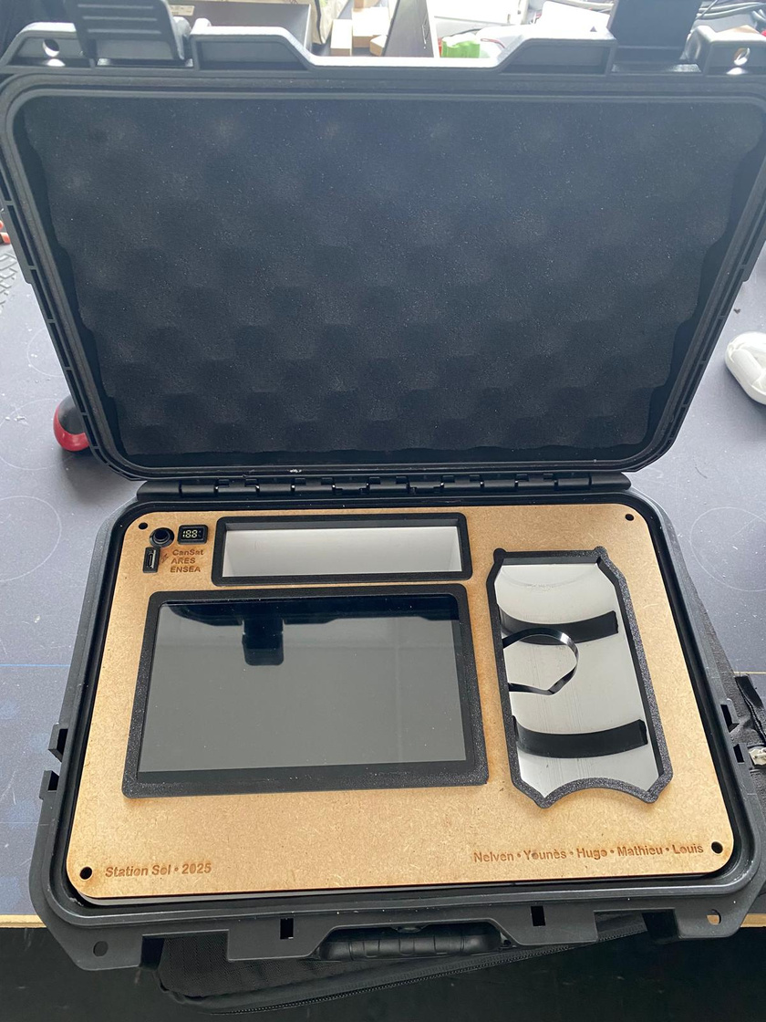
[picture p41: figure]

# STATION

## Comprendre la mécanique Se familiariser avec “l’OS” Modèle de base pour la future station

# PROGRAMMING

## Ecrire le code pour tester les composants Developper les programmes pour le pilotage du cansat Assistance programmation pour la communication

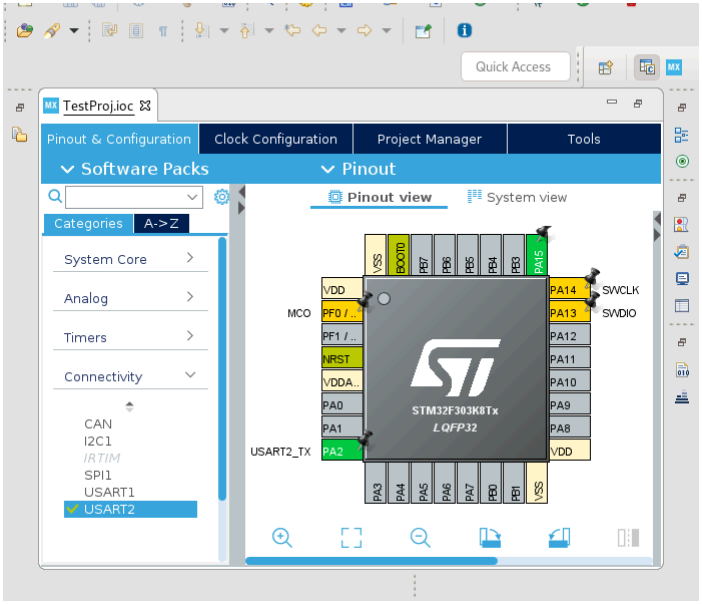
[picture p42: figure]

## STM32 IDE

# ELECTRONIC DESIGN

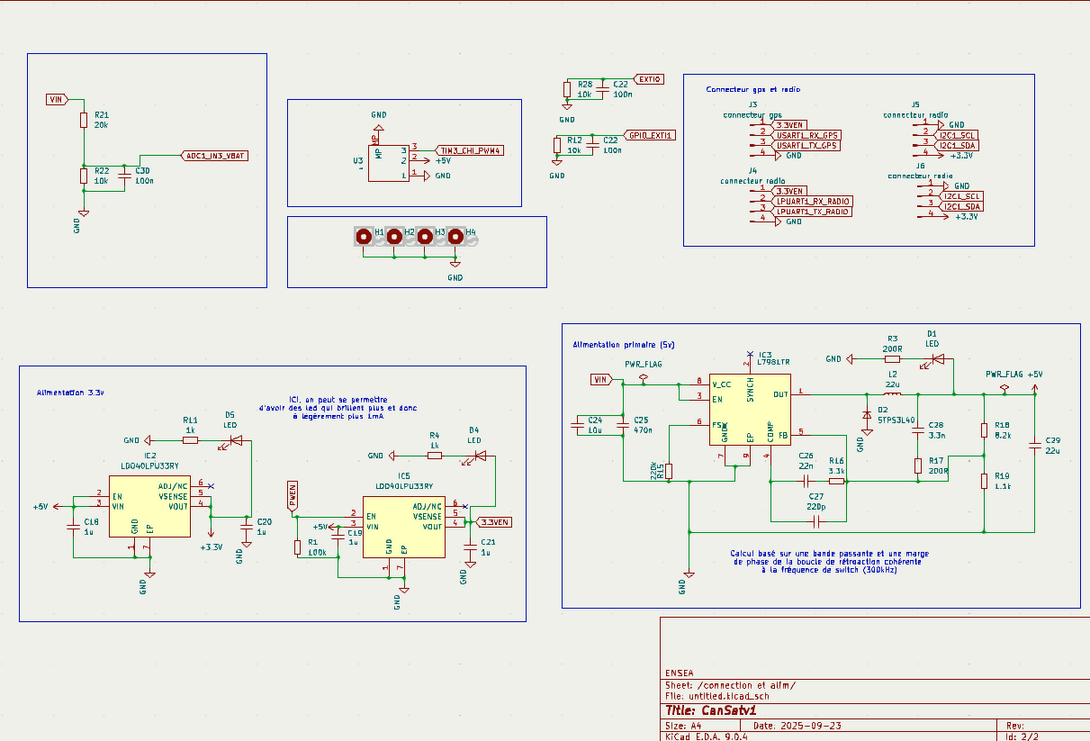
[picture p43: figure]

## Etude du PCB de l’année dernière Test des composants Compréhension des choix réalisés Réflexion concernant l’ajout ou la suppression de composants

# ELECTRONIC DESIGN

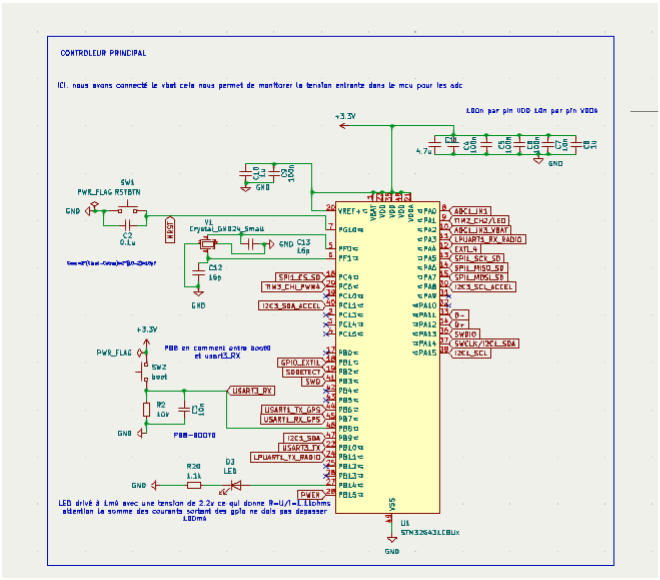
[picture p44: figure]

# STM32G431CBU

# Merci

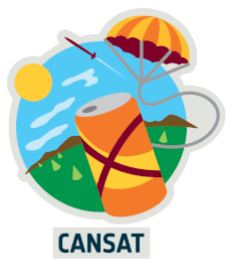
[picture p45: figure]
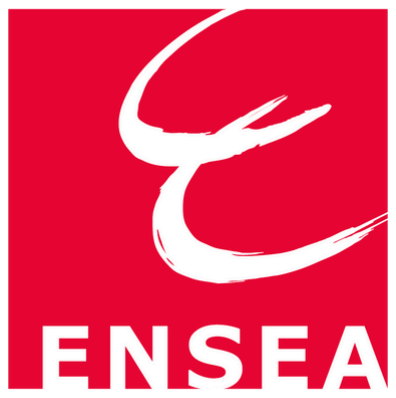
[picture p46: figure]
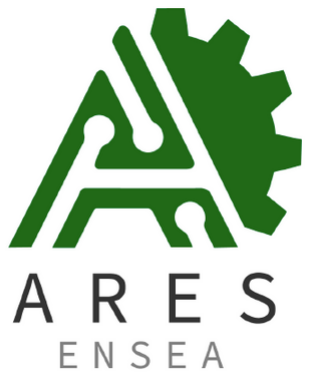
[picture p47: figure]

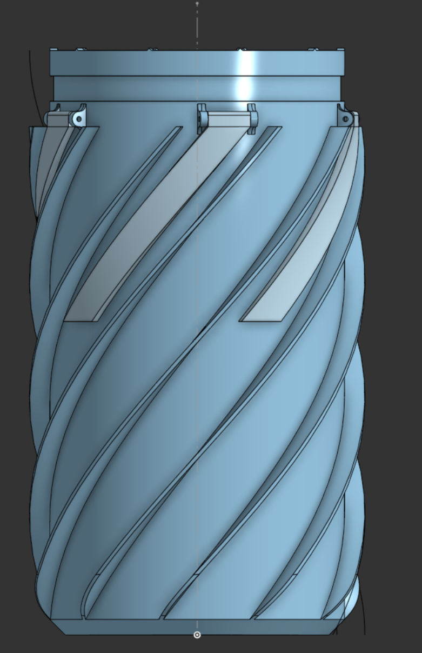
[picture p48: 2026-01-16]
IMG/Mechanical_body.png

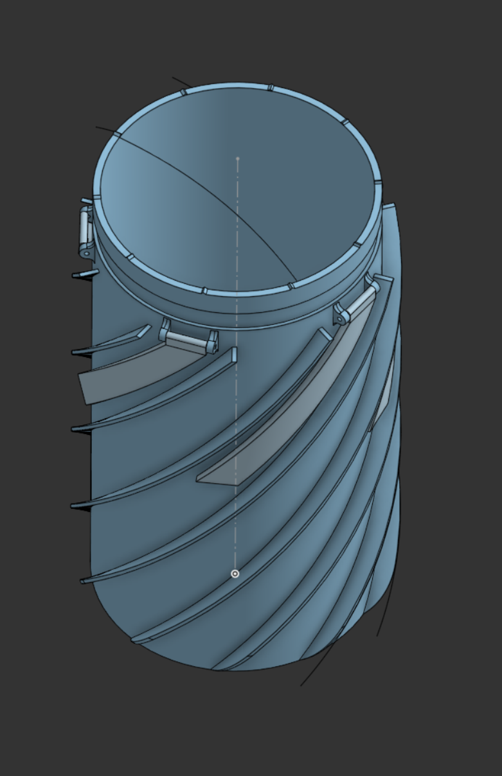
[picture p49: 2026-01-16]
IMG/Mechanical_top.png

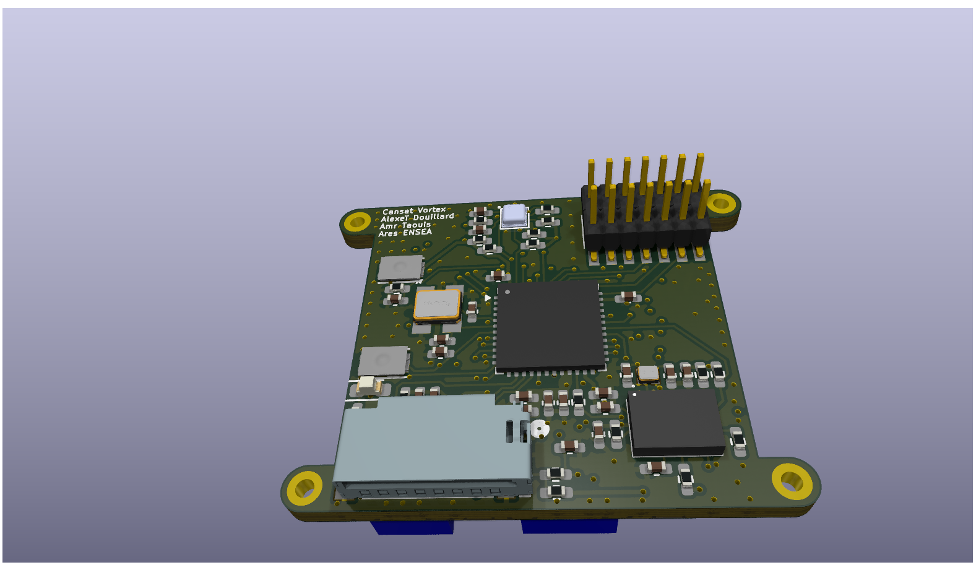
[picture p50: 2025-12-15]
Documents/Pictures/Cansat_PCB.png

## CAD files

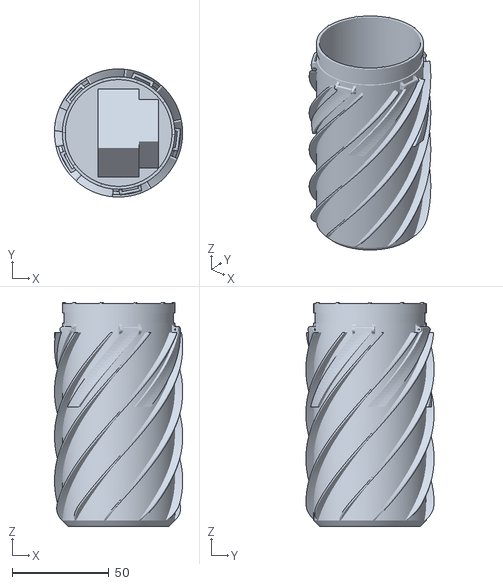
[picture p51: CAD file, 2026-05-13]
Firmware/satellite_telemetry/GUI/Corps1.stl
66.1 x 66.0 x 115.5

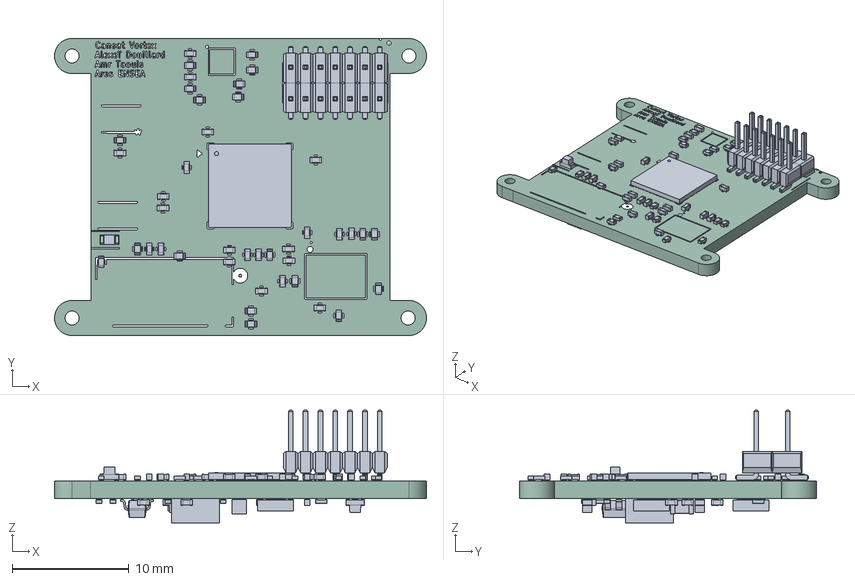
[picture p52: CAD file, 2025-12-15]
Hardware/PCB/Cansat_PCB_V3/Cansat_PCB_V3.step
31.8 x 25.4 x 9.65 mm
C_0402_1005Metric x 29
R_0402_1005Metric x 26
LED_0603_1608Metric x 3
UFQFPN-48_7X7X0P55MM
CON14_2X7_DUK_FTSH_SAI
DFN6_3X3_STM x 2
C_0805_2012Metric
body_SSMC_4020
land_pattern_SSMC_4020 x 2
SOT-23-6
Cansat_PCB_silkscreen x 2
Cansat_PCB_PCB

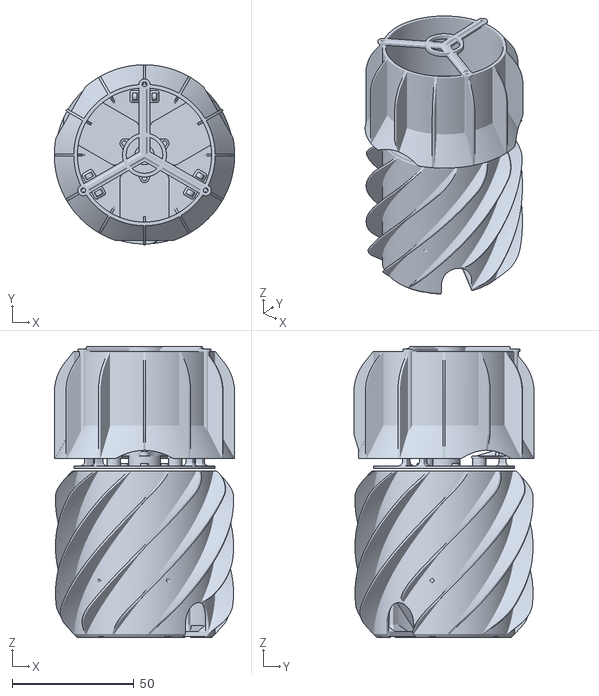
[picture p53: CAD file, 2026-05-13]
Firmware/satellite_telemetry/GUI/Corps.stl
74.0 x 74.0 x 119.4

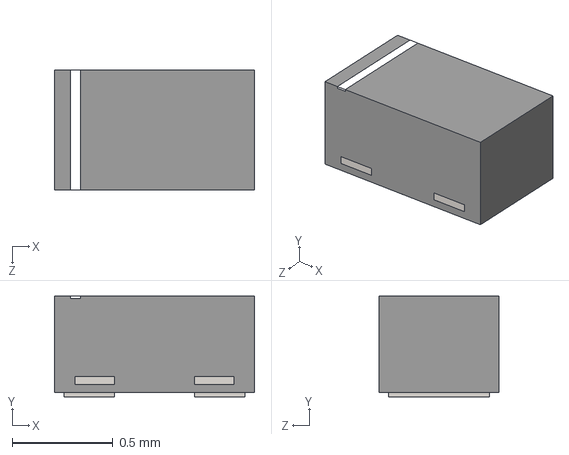
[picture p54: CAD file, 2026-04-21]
Hardware/PCB/Custom_library/New_imports/3D_models/SPHV12-01ETG.stp
0.995 x 0.5 x 0.595 mm

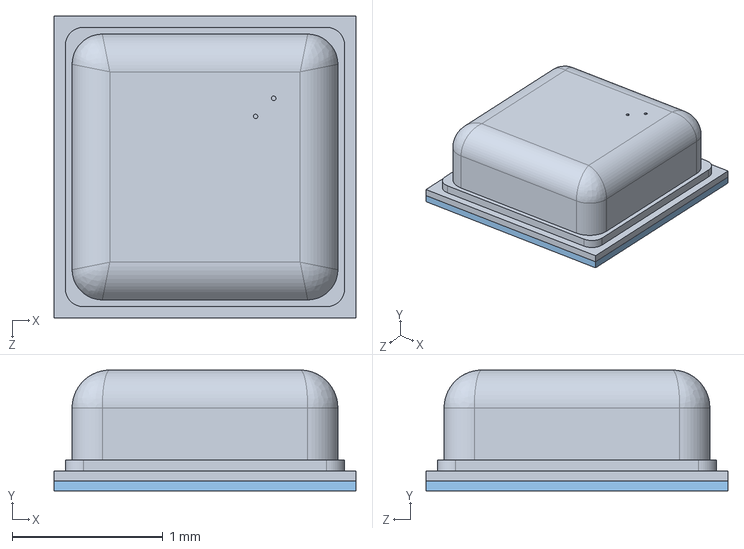
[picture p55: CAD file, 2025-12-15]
Hardware/PCB/Custom_library/New_imports/3D_models/BMP581.STEP
2.00 x 0.801 x 2.00 mm

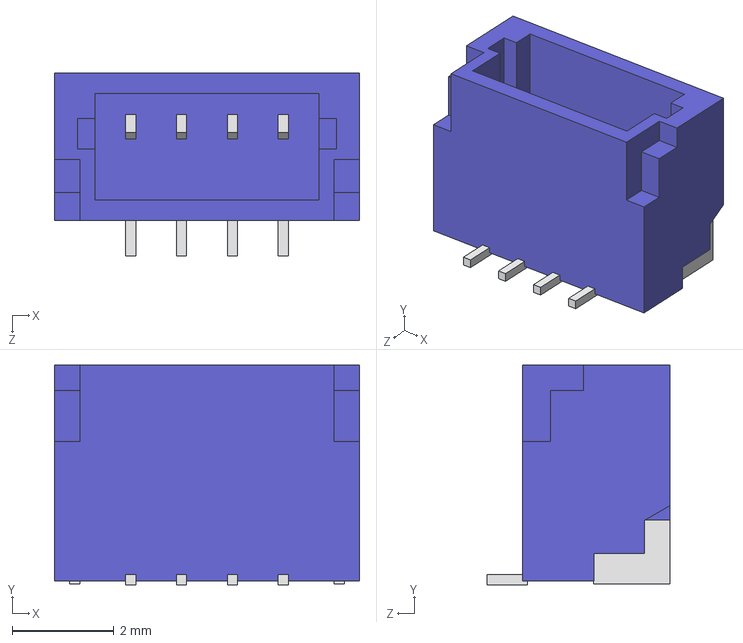
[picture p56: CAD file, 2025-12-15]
Hardware/PCB/Custom_library/New_imports/3D_models/BM04B-SRSS-TB.STEP
6.00 x 4.32 x 3.60 mm

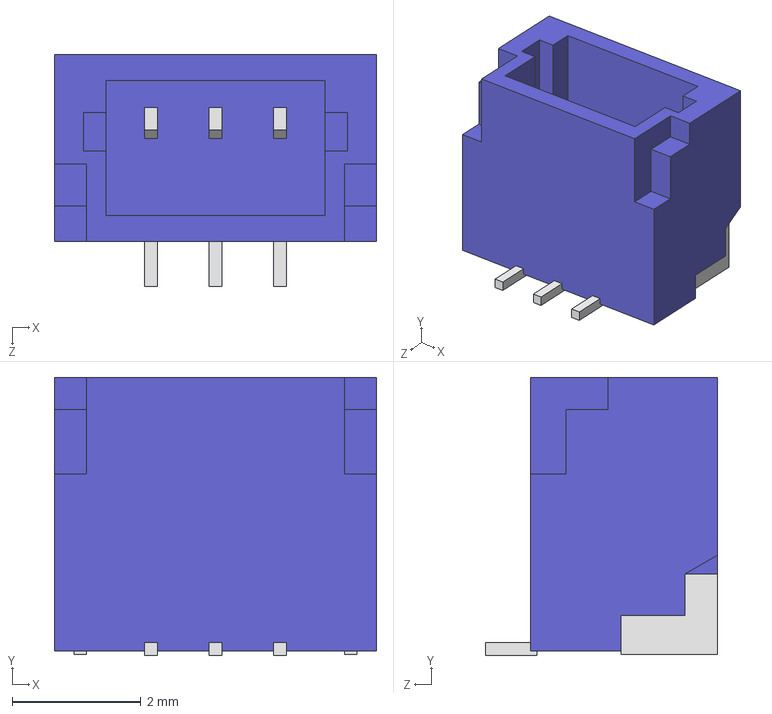
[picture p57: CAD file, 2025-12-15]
Hardware/PCB/Custom_library/New_imports/3D_models/BM03B-SRSS-TB.STEP
5.00 x 4.32 x 3.60 mm

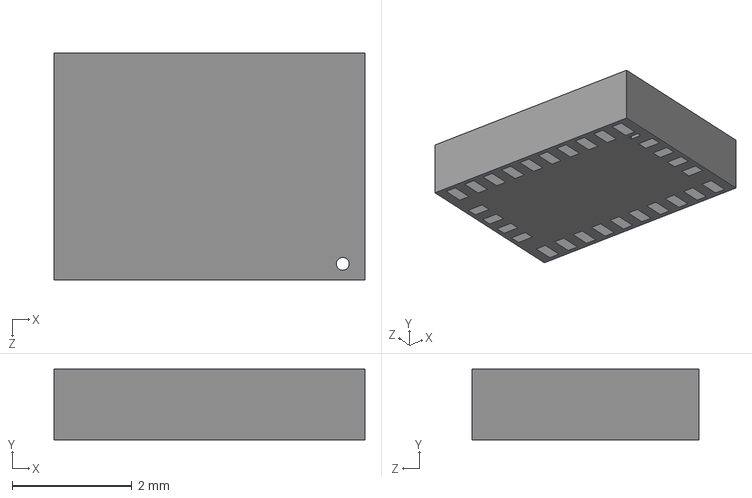
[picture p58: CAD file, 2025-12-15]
Hardware/PCB/Custom_library/New_imports/3D_models/BNO055.STEP
5.20 x 1.18 x 3.80 mm

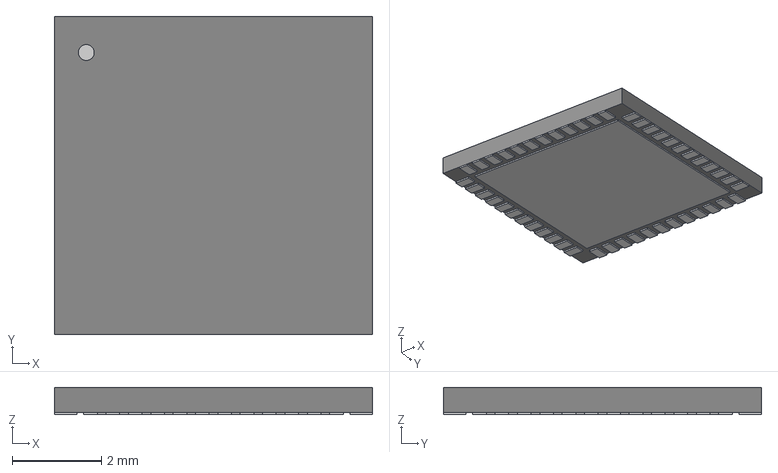
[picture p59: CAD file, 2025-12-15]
Hardware/PCB/Custom_library/New_imports/3D_models/UFQFPN-48_7X7X0P55MM.step
7.11 x 7.11 x 0.612 mm

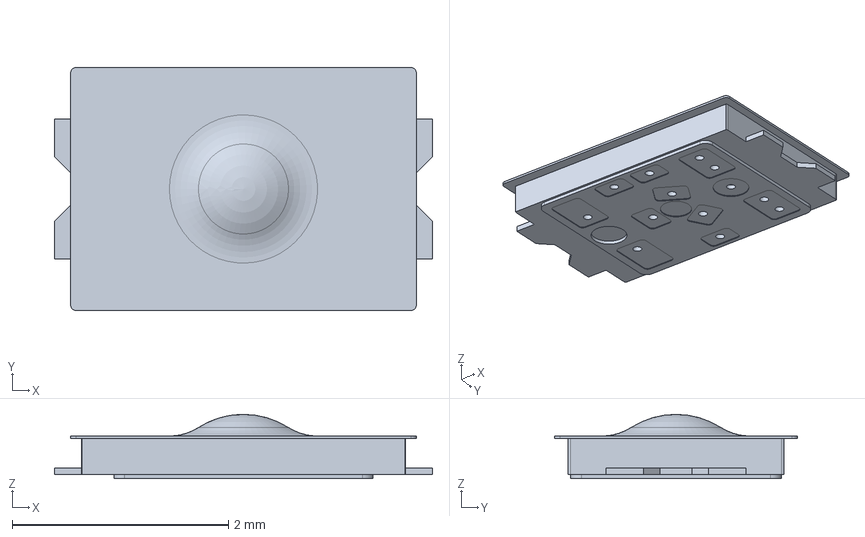
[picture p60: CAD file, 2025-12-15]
Hardware/PCB/Custom_library/New_imports/3D_models/KXT321LHS.stp
3.50 x 2.25 x 0.595 mm

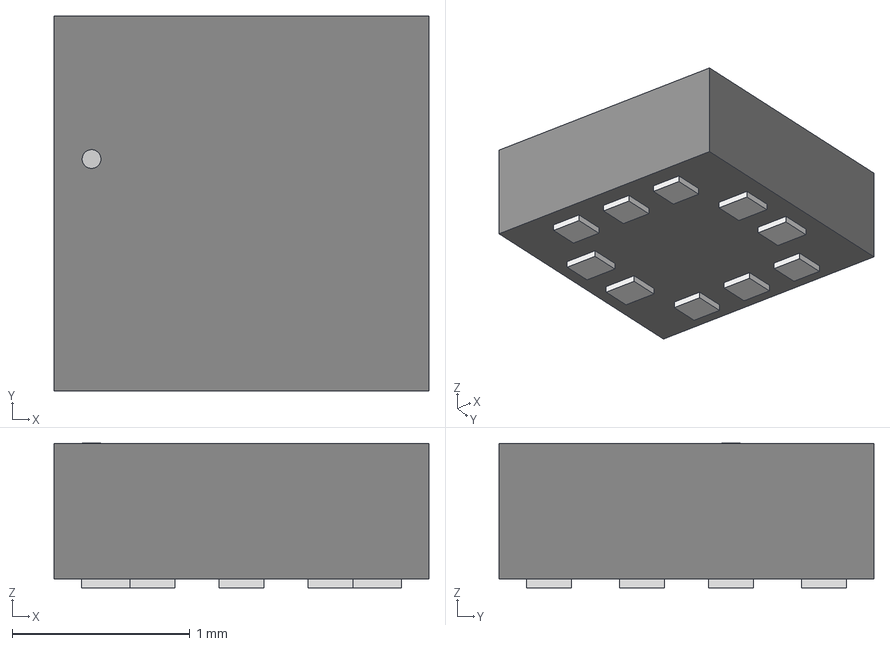
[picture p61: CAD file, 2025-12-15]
Hardware/PCB/Custom_library/New_imports/3D_models/QFN10_BMP581_BOS.step
2.11 x 2.11 x 0.815 mm

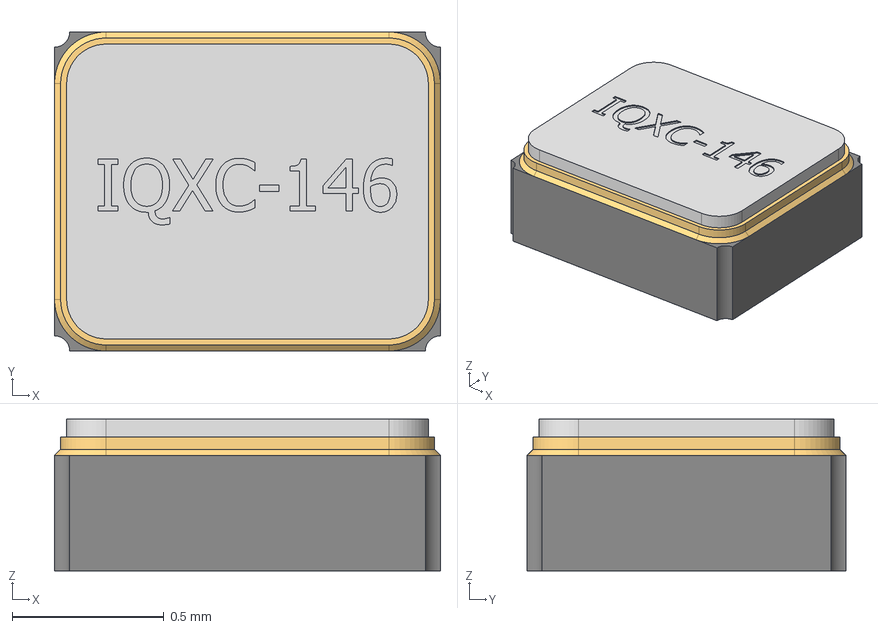
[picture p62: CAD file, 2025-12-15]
Hardware/PCB/Custom_library/New_imports/3D_models/Download_STP_830108091501_IMU_osc.stp
1.27 x 1.05 x 0.5 mm
Pins
Cover

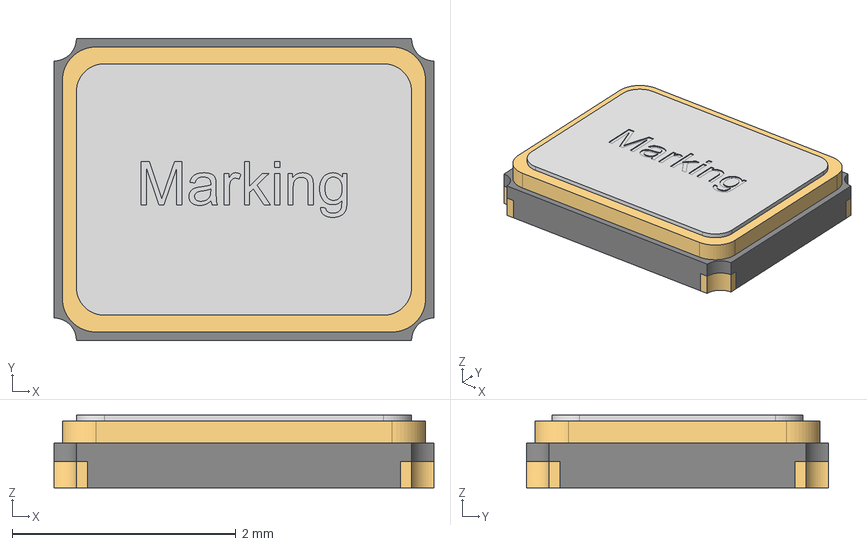
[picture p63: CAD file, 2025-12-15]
Hardware/PCB/Custom_library/New_imports/3D_models/Download_STP_830069882 (rev1).stp
3.40 x 2.70 x 0.65 mm
Pins
Cover

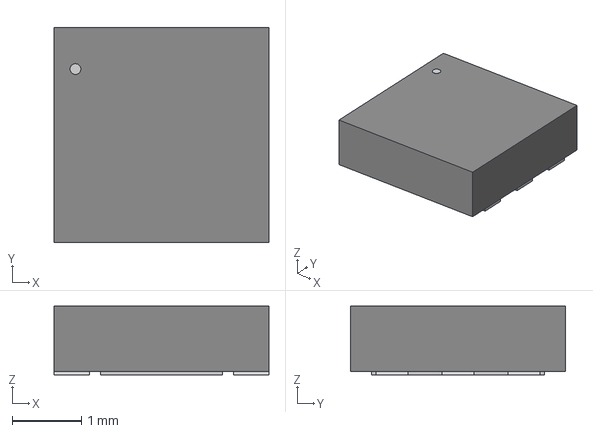
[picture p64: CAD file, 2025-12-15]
Hardware/PCB/Custom_library/New_imports/3D_models/DFN6_3X3_STM.step
3.10 x 3.10 x 0.993 mm

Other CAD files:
Hardware/PCB/Custom_library/New_imports/3D_models/Molex.stp
Hardware/PCB/Custom_library/New_imports/3D_models/Download_STP_WE-MAPI_4020 (rev1).stp
Hardware/PCB/Custom_library/New_imports/3D_models/BM07B-SRSS-TB.STEP
Hardware/PCB/Custom_library/New_imports/3D_models/CON14_2X7_DUK_FTSH_SAI.step
Hardware/PCB/Custom_library/New_imports/3D_models/0467001.NRHF.stp

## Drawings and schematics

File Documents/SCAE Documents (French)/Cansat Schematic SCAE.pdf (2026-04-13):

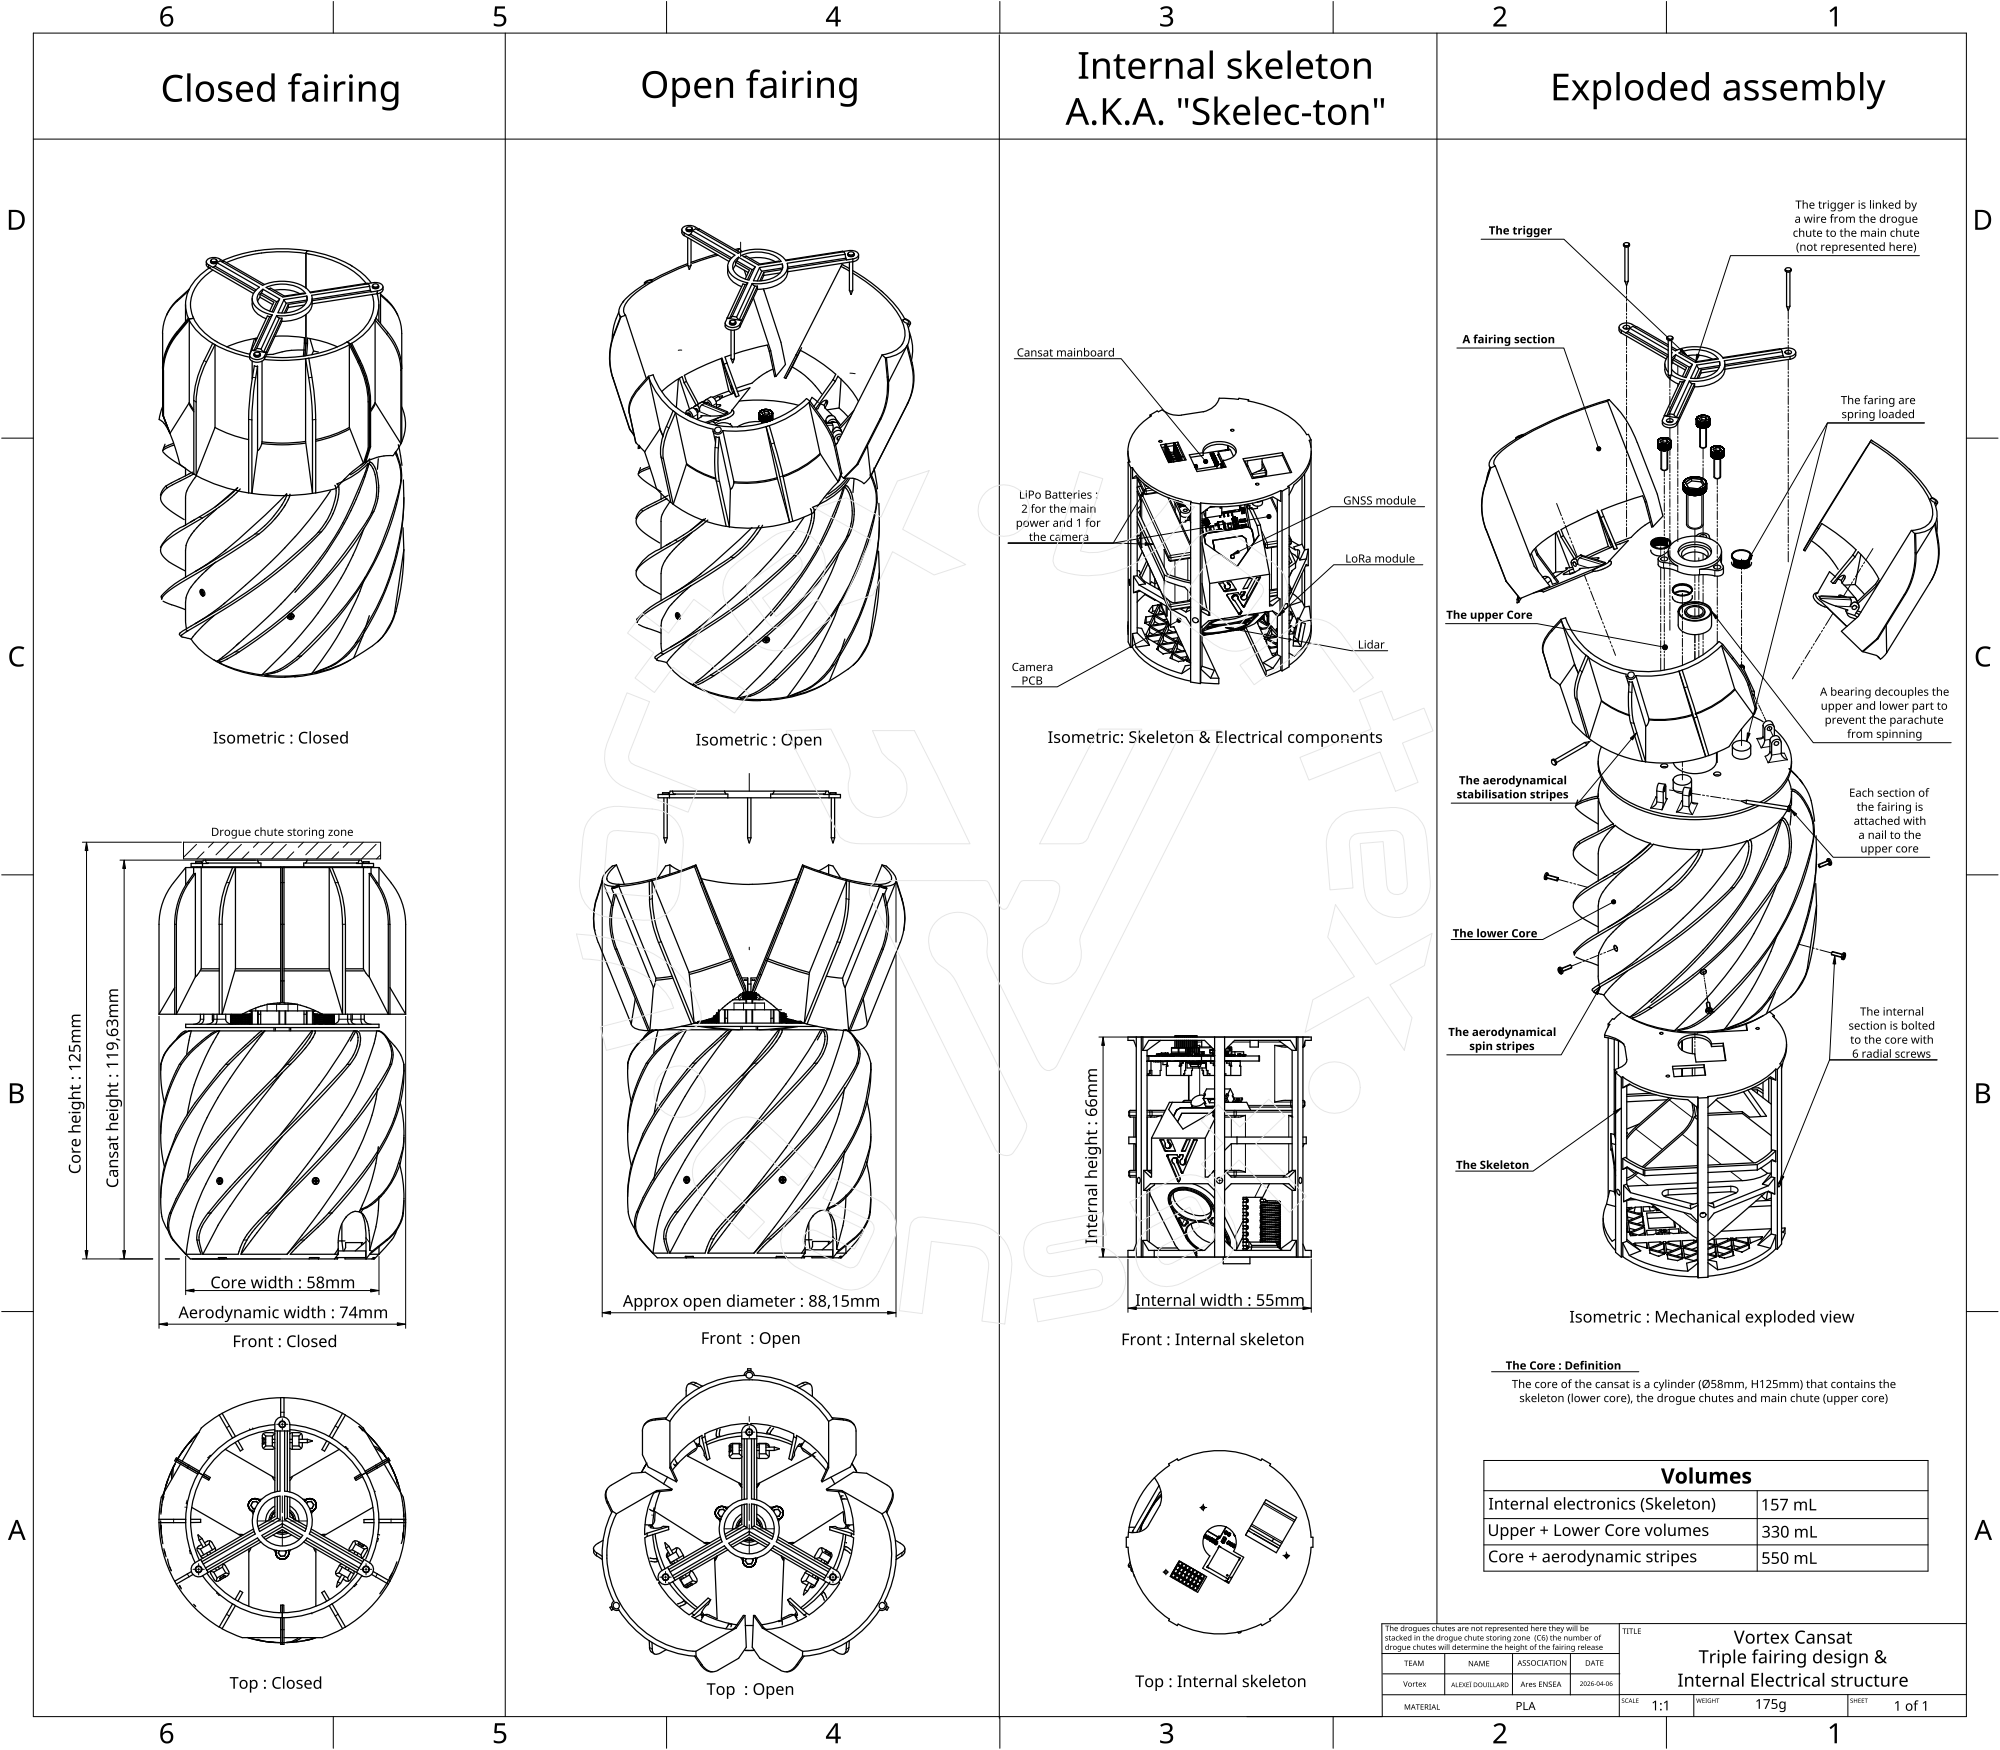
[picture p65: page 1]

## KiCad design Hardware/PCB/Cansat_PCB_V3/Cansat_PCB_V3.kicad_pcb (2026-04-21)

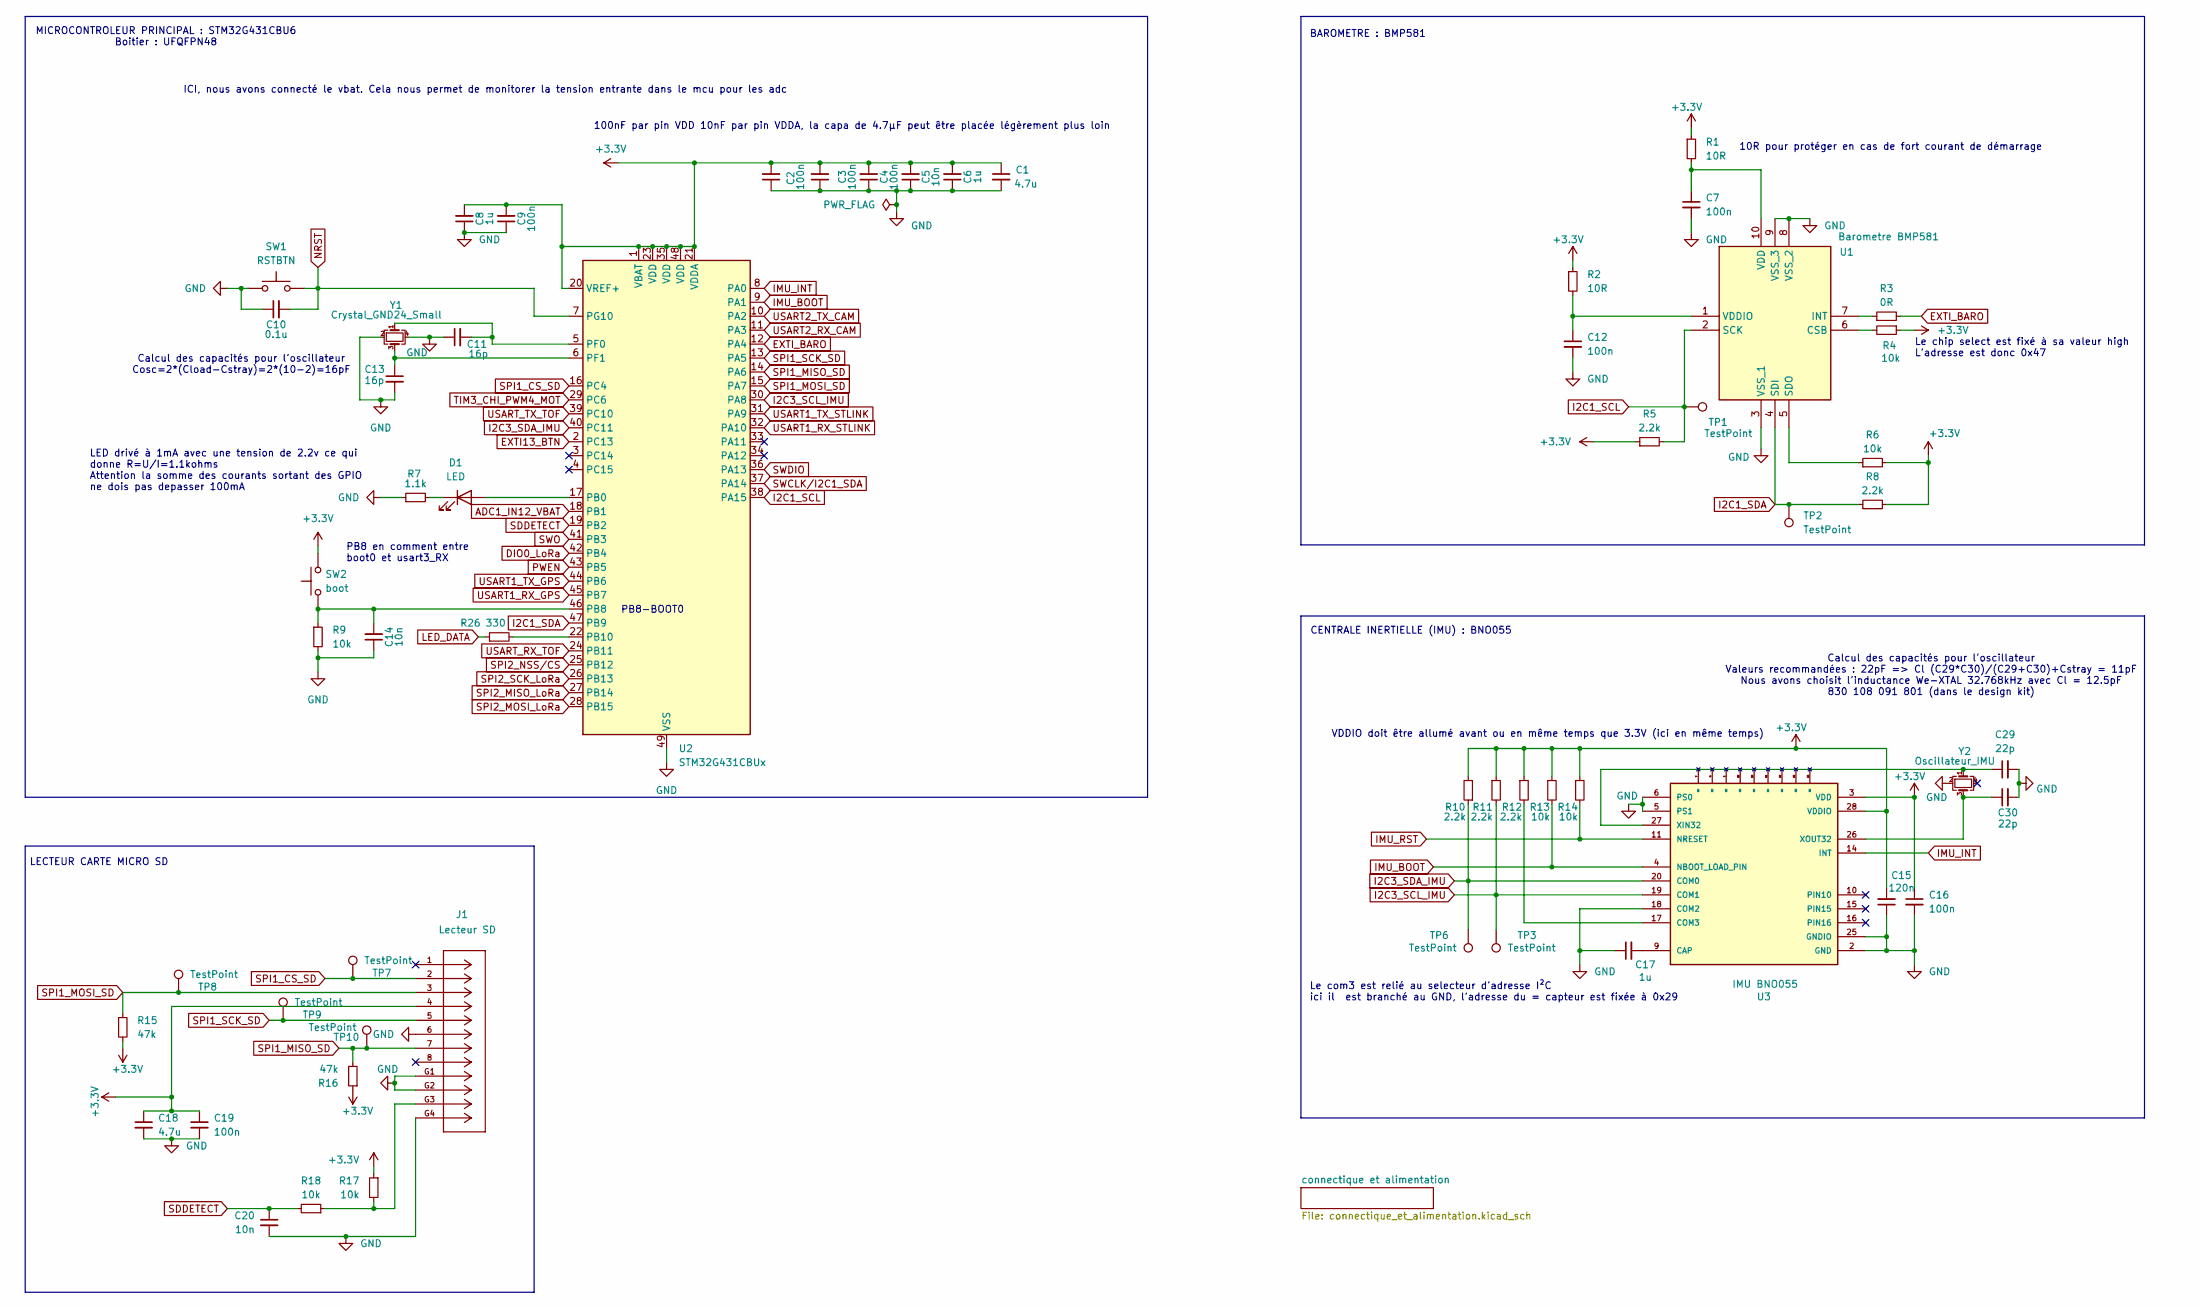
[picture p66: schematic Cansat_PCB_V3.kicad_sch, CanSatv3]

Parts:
C1, C18: 4.7u; C_0402_1005Metric_Pad0.74x0.62mm_HandSolder
C2, C3, C4, C7, C9, C12, C16, C19: 100n; C_0402_1005Metric_Pad0.74x0.62mm_HandSolder
C5, C14, C20: 10n; C_0402_1005Metric_Pad0.74x0.62mm_HandSolder
C6, C8, C17: 1u; C_0402_1005Metric_Pad0.74x0.62mm_HandSolder
C10: 0.1u; C_0402_1005Metric_Pad0.74x0.62mm_HandSolder
C11, C13: 16p; C_0402_1005Metric_Pad0.74x0.62mm_HandSolder
C15: 120n; C_0402_1005Metric_Pad0.74x0.62mm_HandSolder
C29, C30: 22p; C_0402_1005Metric_Pad0.74x0.62mm_HandSolder
D1: LED; LED_0603_1608Metric_Pad1.05x0.95mm_HandSolder
J1: Lecteur SD; CONN12_47309-2651_MOL; Manufacturer_Part_Number 47309-2651
R1, R2: 10R; R_0402_1005Metric_Pad0.72x0.64mm_HandSolder
R3: 0R; R_0402_1005Metric_Pad0.72x0.64mm_HandSolder
R4, R6, R9, R13, R14, R17, R18: 10k; R_0402_1005Metric_Pad0.72x0.64mm_HandSolder
R5, R8, R10, R11, R12: 2.2k; R_0402_1005Metric_Pad0.72x0.64mm_HandSolder
R7: 1.1k; R_0402_1005Metric_Pad0.72x0.64mm_HandSolder
R15, R16: 47k; R_0402_1005Metric_Pad0.72x0.64mm_HandSolder
R26: 330; R_0402_1005Metric_Pad0.72x0.64mm_HandSolder
SW1: RSTBTN; KXT 321 LHS_CNK
SW2: boot; KXT 321 LHS_CNK
TP1, TP2, TP3, TP6, TP7, TP8, TP9, TP10: TestPoint; TestPoint_Pad_D1.0mm
U1: Barometre BMP581; BMP581; Manufacturer_Part_Number BMP581; Mouser Part Number 262-BMP581
U2: STM32G431CBUx; QFN-48-1EP_7x7mm_P0.5mm_EP5.6x5.6mm
U3: IMU BNO055; LGA28R50P4X10_380X520X100; Manufacturer_Part_Number BNO055; Mouser Part Number 262-BNO055
Y1: Crystal_GND24_Small; Crystal_SMD_3225-4pin_3.2x2.5mm
Y2: Oscillateur_IMU; WE-XTAL_IQXC-146

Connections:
+3.3V: C1.1, C2.2, C3.2, C4.2, C5.2, C6.2, C8.2, C9.2, C15.2, C16.1, C18.1, C19.1, J1.4, R1.1, R2.1, R4.1, R5.1, R6.2, R8.2, R10.2, R11.1, R12.1, R13.1, R14.1, R15.2, R16.1, R17.1, SW2.2, U2.1 (VBAT), U2.20 (VREF+), U2.21 (VDDA), U2.23 (VDD), U2.35 (VDD), U2.48 (VDD), U3.3 (VDD), U3.28 (VDDIO); also elsewhere on the board
ADC1_IN12_VBAT: U2.18 (PB1); also elsewhere on the board
DIO0_LoRa: U2.42 (PB4); also elsewhere on the board
EXTI13_BTN: U2.2 (PC13); also elsewhere on the board
EXTI_BARO: R3.2, U2.12 (PA4)
GND: C1.2, C2.1, C3.1, C4.1, C5.1, C6.1, C7.2, C8.1, C9.1, C10.1, C11.1, C12.2, C13.2, C14.1, C15.1, C16.2, C17.1, C18.2, C19.2, C20.2, C29.2, C30.2, J1.6, J1.G1, J1.G2, J1.G4, R7.1, R9.2, SW1.1, U1.3 (VSS_1), U1.8 (VSS_2), U1.9 (VSS_3), U2.49 (VSS), U3.2 (GND), U3.5 (PS1), U3.6 (PS0), U3.18 (COM2), U3.25 (GNDIO), Y1.2, Y1.4, Y2.2; also elsewhere on the board
I2C1_SCL: R5.2, TP1.1, U1.2 (SCK), U2.38 (PA15); also elsewhere on the board
I2C1_SDA: R8.1, TP2.1, U1.4 (SDI), U2.47 (PB9); also elsewhere on the board
I2C3_SCL_IMU: R11.2, TP3.1, U2.30 (PA8), U3.19 (COM1)
I2C3_SDA_IMU: R10.1, TP6.1, U2.40 (PC11), U3.20 (COM0)
IMU_BOOT: R13.2, U2.9 (PA1), U3.4 (NBOOT_LOAD_PIN)
IMU_INT: U2.8 (PA0), U3.14 (INT)
IMU_RST: R14.2, U3.11 (NRESET)
LED_DATA: R26.1; also elsewhere on the board
NRST: C10.2, SW1.2, U2.7 (PG10); also elsewhere on the board
unnamed: D1.2 (A), U2.17 (PB0)
unnamed: D1.1 (K), R7.2
unnamed: J1.G3, R17.2, R18.1
unnamed: R4.2, U1.6 (CSB)
unnamed: R3.1, U1.7 (INT)
unnamed: R6.1, U1.5 (SDO)
unnamed: C7.1, R1.2, U1.10 (VDD)
unnamed: C12.1, R2.2, U1.1 (VDDIO)
unnamed: C14.2, R9.1, SW2.1, U2.46 (PB8)
unnamed: R26.2, U2.22 (PB10)
unnamed: C11.2, U2.5 (PF0), Y1.1
unnamed: C13.1, U2.6 (PF1), Y1.3
unnamed: C17.2, U3.9 (CAP)
unnamed: R12.2, U3.17 (COM3)
unnamed: C29.1, U3.27 (XIN32), Y2.1
unnamed: C30.1, U3.26 (XOUT32), Y2.3
PWEN: U2.43 (PB5); also elsewhere on the board
SDDETECT: C20.1, R18.2, U2.19 (PB2)
SPI1_CS_SD: J1.2, TP7.1, U2.16 (PC4)
SPI1_MISO_SD: J1.7, R16.2, TP10.1, U2.14 (PA6)
SPI1_MOSI_SD: J1.3, R15.1, TP8.1, U2.15 (PA7)
SPI1_SCK_SD: J1.5, TP9.1, U2.13 (PA5)
SPI2_MISO_LoRa: U2.27 (PB14); also elsewhere on the board
SPI2_MOSI_LoRa: U2.28 (PB15); also elsewhere on the board
SPI2_NSS/CS: U2.25 (PB12); also elsewhere on the board
SPI2_SCK_LoRa: U2.26 (PB13); also elsewhere on the board
SWCLK/I2C1_SDA: U2.37 (PA14); also elsewhere on the board
SWDIO: U2.36 (PA13); also elsewhere on the board
SWO: U2.41 (PB3); also elsewhere on the board
TIM3_CHI_PWM4_MOT: U2.29 (PC6); also elsewhere on the board
USART1_RX_GPS: U2.45 (PB7); also elsewhere on the board
USART1_RX_STLINK: U2.32 (PA10); also elsewhere on the board
USART1_TX_GPS: U2.44 (PB6); also elsewhere on the board
USART1_TX_STLINK: U2.31 (PA9); also elsewhere on the board
USART2_RX_CAM: U2.11 (PA3); also elsewhere on the board
USART2_TX_CAM: U2.10 (PA2); also elsewhere on the board
USART_RX_TOF: U2.24 (PB11); also elsewhere on the board
USART_TX_TOF: U2.39 (PC10); also elsewhere on the board

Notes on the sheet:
BAROMETRE : BMP581
100nF par pin VDD 10nF par pin VDDA, la capa de 4.7µF peut être placée légèrement plus loin
Le com3 est relié au selecteur d'adresse I²C ici il est branché au GND, l'adresse du = capteur est fixée à 0x29
Calcul des capacités pour l'oscillateur Cosc=2*(Cload-Cstray)=2*(10-2)=16pF
10R pour protéger en cas de fort courant de démarrage
Le chip select est fixé à sa valeur high L'adresse est donc 0x47
VDDIO doit être allumé avant ou en même temps que 3.3V (ici en même temps)
Calcul des capacités pour l'oscillateur Valeurs recommandées : 22pF => Cl (C29*C30)/(C29+C30)+Cstray = 11pF Nous avons choisit l'inductance We-XTAL 32.768kHz avec Cl = 12.5pF 830 108 091 801 (dans le design kit)
MICROCONTROLEUR PRINCIPAL : STM32G431CBU6 Boitier : UFQFPN48
CENTRALE INERTIELLE (IMU) : BNO055
PB8-BOOT0
PB8 en comment entre boot0 et usart3_RX
ICI, nous avons connecté le vbat. Cela nous permet de monitorer la tension entrante dans le mcu pour les adc
LED drivé à 1mA avec une tension de 2.2v ce qui donne R=U/I=1.1kohms Attention la somme des courants sortant des GPIO ne dois pas depasser 100mA
LECTEUR CARTE MICRO SD

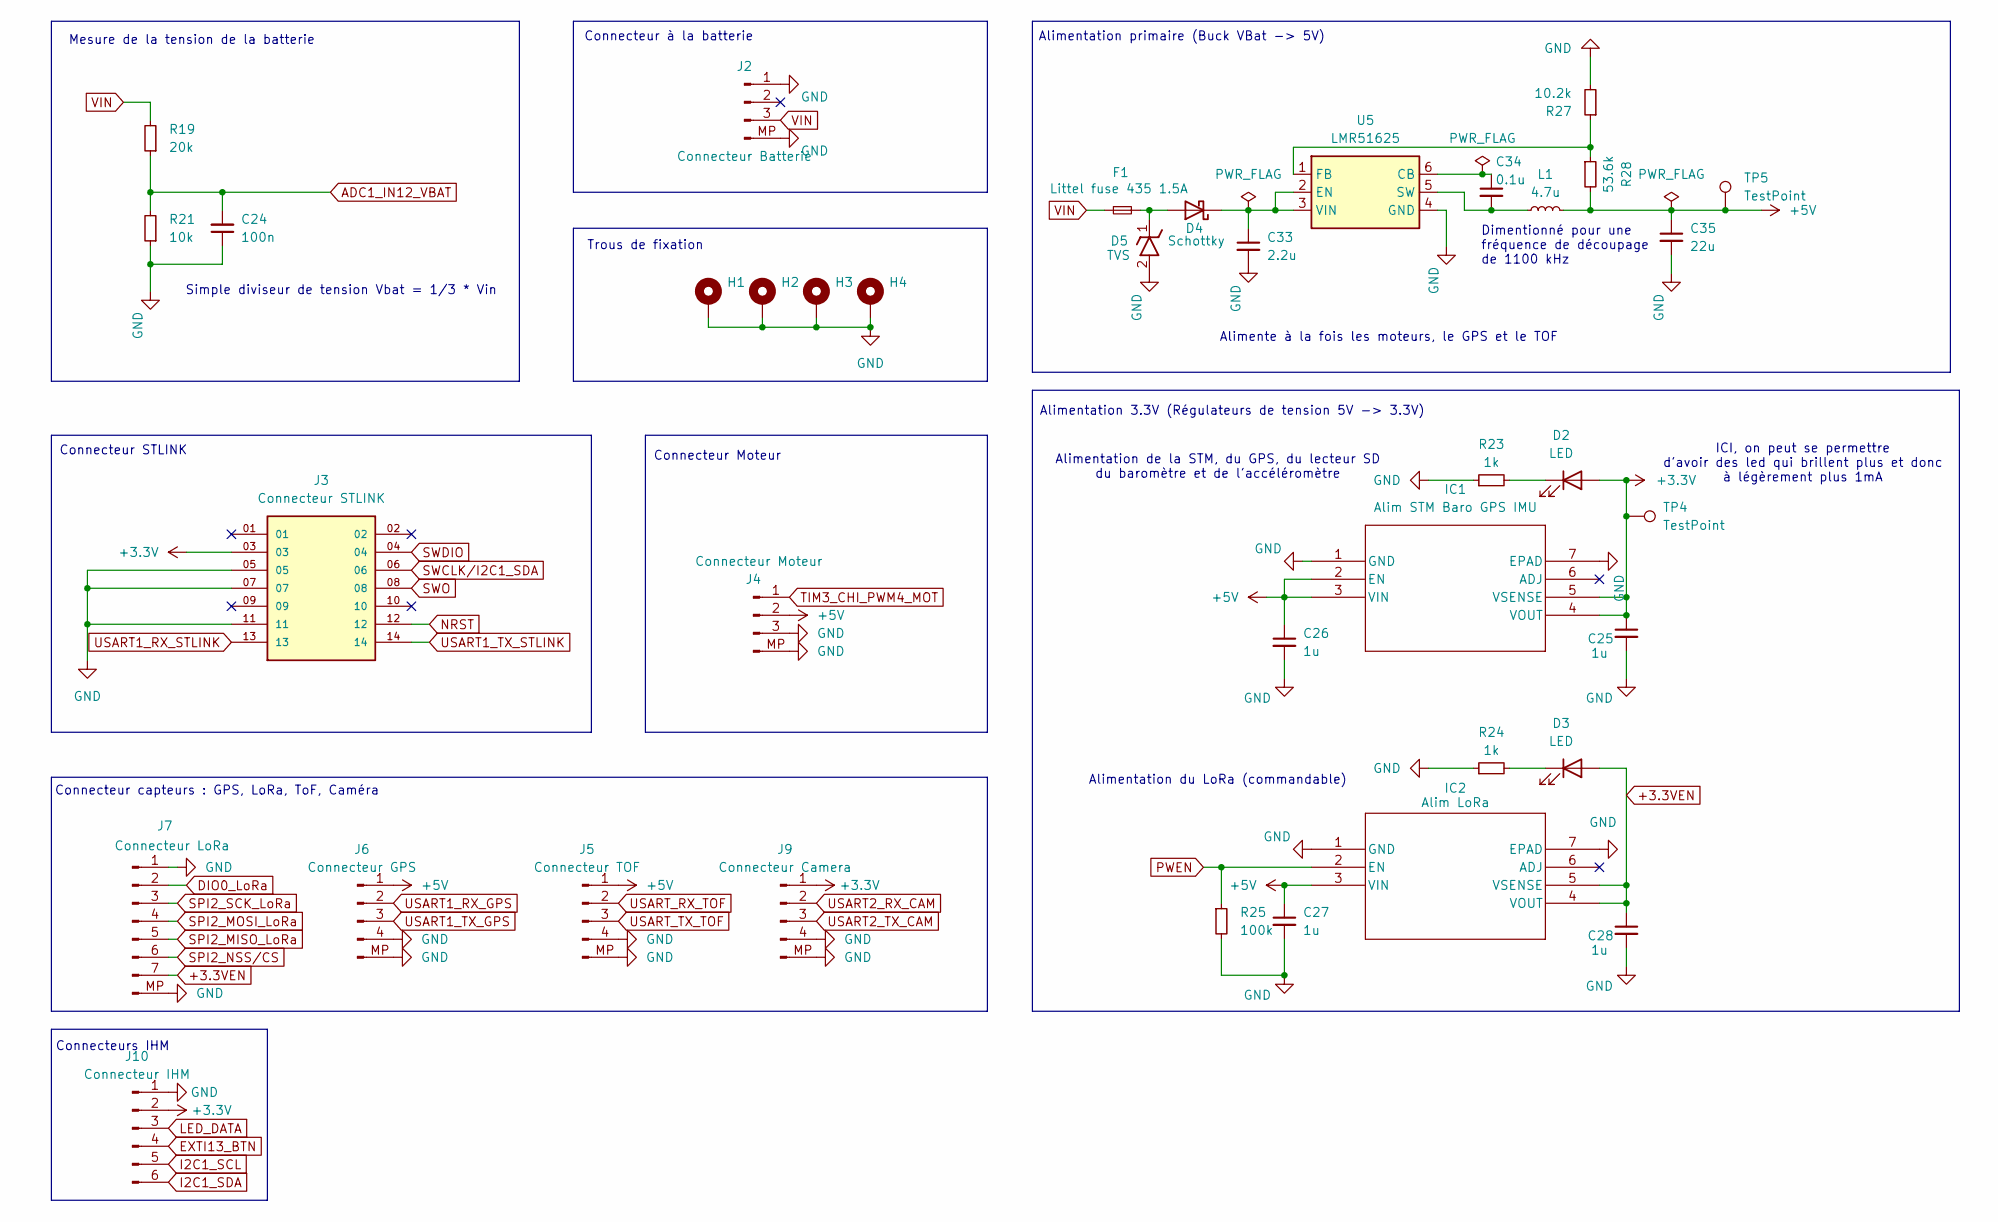
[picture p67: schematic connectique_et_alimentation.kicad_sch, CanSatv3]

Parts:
C24: 100n; C_0402_1005Metric_Pad0.74x0.62mm_HandSolder
C25, C26, C27, C28: 1u; C_0402_1005Metric_Pad0.74x0.62mm_HandSolder
C33: 2.2u; C_0402_1005Metric_Pad0.74x0.62mm_HandSolder
C34: 0.1u; C_0402_1005Metric_Pad0.74x0.62mm_HandSolder
C35: 22u; C_0805_2012Metric_Pad1.18x1.45mm_HandSolder
D2, D3: LED; LED_0603_1608Metric_Pad1.05x0.95mm_HandSolder
D4: Schottky; D_SOD-882D
D5: TVS; SPHV12-01ETG; Manufacturer_Part_Number SPHV12-01ETG
F1: Littel fuse 435 1.5A; FUSC1608X43N
H1, H2, H3, H4: MountingHole_Pad; MountingHole_2.2mm_M2_ISO7380_Pad
IC1: Alim STM Baro GPS IMU; DFN6_3X3_STM; Manufacturer_Part_Number LDO40LPU33RY; Mouser Part Number 511-LDO40LPU33RY
IC2: Alim LoRa; DFN6_3X3_STM; Manufacturer_Part_Number LDO40LPU33RY; Mouser Part Number 511-LDO40LPU33RY
J2: Connecteur Batterie; JST_SH_BM03B-SRSS-TB_1x03-1MP_P1.00mm_Vertical
J3: Connecteur STLINK; FTSH-107-XX-YYY-DV-K; PARTREV H
J4: Connecteur Moteur; JST_SH_BM03B-SRSS-TB_1x03-1MP_P1.00mm_Vertical
J5: Connecteur TOF; JST_SH_BM04B-SRSS-TB_1x04-1MP_P1.00mm_Vertical
J6: Connecteur GPS; JST_SH_BM04B-SRSS-TB_1x04-1MP_P1.00mm_Vertical
J7: Connecteur LoRa; JST_SH_BM07B-SRSS-TB_1x07-1MP_P1.00mm_Vertical
J9: Connecteur Camera; JST_SH_BM04B-SRSS-TB_1x04-1MP_P1.00mm_Vertical
J10: Connecteur IHM; JST_SH_BM06B-SRSS-TB_1x06-1MP_P1.00mm_Vertical
L1: 4.7u; IND_WE-MAPI_4020_WRE
R19: 20k; R_0402_1005Metric_Pad0.72x0.64mm_HandSolder
R21: 10k; R_0402_1005Metric_Pad0.72x0.64mm_HandSolder
R23, R24: 1k; R_0402_1005Metric_Pad0.72x0.64mm_HandSolder
R25: 100k; R_0402_1005Metric_Pad0.72x0.64mm_HandSolder
R27: 10.2k; R_0402_1005Metric_Pad0.72x0.64mm_HandSolder
R28: 53.6k; R_0402_1005Metric_Pad0.72x0.64mm_HandSolder
TP4, TP5: TestPoint; TestPoint_Pad_1.5x1.5mm
U5: LMR51625; SOT-23-6

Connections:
+3.3V: C25.1, D2.2 (A), IC1.4 (VOUT), IC1.5 (VSENSE), J3.03, J9.1, J10.2, TP4.1; also elsewhere on the board
+3.3VEN: C28.1, D3.2 (A), IC2.4 (VOUT), IC2.5 (VSENSE), J7.7
+5V: C26.1, C27.1, C35.1, IC1.2 (EN), IC1.3 (VIN), IC2.3 (VIN), J4.2, J5.1, J6.1, L1.2, R28.2, TP5.1
ADC1_IN12_VBAT: C24.2, R19.1, R21.2; also elsewhere on the board
DIO0_LoRa: J7.2; also elsewhere on the board
EXTI13_BTN: J10.4; also elsewhere on the board
GND: C24.1, C25.2, C26.2, C27.2, C28.2, C33.2, C35.2, D5.2 (A), H1.1, H2.1, H3.1, H4.1, IC1.1 (GND), IC1.7 (EPAD), IC2.1 (GND), IC2.7 (EPAD), J2.1, J2.MP, J3.05, J3.07, J3.11, J4.3, J4.MP, J5.4, J5.MP, J6.4, J6.MP, J7.1, J7.MP, J9.4, J9.MP, J10.1, R21.1, R23.1, R24.1, R25.2, R27.2, U5.4 (GND); also elsewhere on the board
I2C1_SCL: J10.5; also elsewhere on the board
I2C1_SDA: J10.6; also elsewhere on the board
LED_DATA: J10.3; also elsewhere on the board
NRST: J3.12; also elsewhere on the board
unnamed: D2.1 (K), R23.2
unnamed: D3.1 (K), R24.2
unnamed: D4.2 (A), D5.1 (K), F1.2
unnamed: C33.1, D4.1 (K), U5.2 (EN), U5.3 (VIN)
unnamed: C34.1, U5.6 (CB)
unnamed: R27.1, R28.1, U5.1 (FB)
unnamed: C34.2, L1.1, U5.5 (SW)
PWEN: IC2.2 (EN), R25.1; also elsewhere on the board
SPI2_MISO_LoRa: J7.5; also elsewhere on the board
SPI2_MOSI_LoRa: J7.4; also elsewhere on the board
SPI2_NSS/CS: J7.6; also elsewhere on the board
SPI2_SCK_LoRa: J7.3; also elsewhere on the board
SWCLK/I2C1_SDA: J3.06; also elsewhere on the board
SWDIO: J3.04; also elsewhere on the board
SWO: J3.08; also elsewhere on the board
TIM3_CHI_PWM4_MOT: J4.1; also elsewhere on the board
USART1_RX_GPS: J6.2; also elsewhere on the board
USART1_RX_STLINK: J3.13; also elsewhere on the board
USART1_TX_GPS: J6.3; also elsewhere on the board
USART1_TX_STLINK: J3.14; also elsewhere on the board
USART2_RX_CAM: J9.2; also elsewhere on the board
USART2_TX_CAM: J9.3; also elsewhere on the board
USART_RX_TOF: J5.2; also elsewhere on the board
USART_TX_TOF: J5.3; also elsewhere on the board
VIN: F1.1, J2.3, R19.2

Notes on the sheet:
Alimentation de la STM, du GPS, du lecteur SD du baromètre et de l'accéléromètre
Alimentation du LoRa (commandable)
Trous de fixation
Alimente à la fois les moteurs, le GPS et le TOF
Connecteur capteurs : GPS, LoRa, ToF, Caméra
Simple diviseur de tension Vbat = 1/3 * Vin
Connecteur à la batterie
Dimentionné pour une fréquence de découpage de 1100 kHz
Connecteur Moteur
Mesure de la tension de la batterie
ICI, on peut se permettre d'avoir des led qui brillent plus et donc à légèrement plus 1mA
Connecteurs IHM
Alimentation 3.3V (Régulateurs de tension 5V -> 3.3V)
Connecteur STLINK
Alimentation primaire (Buck VBat -> 5V)

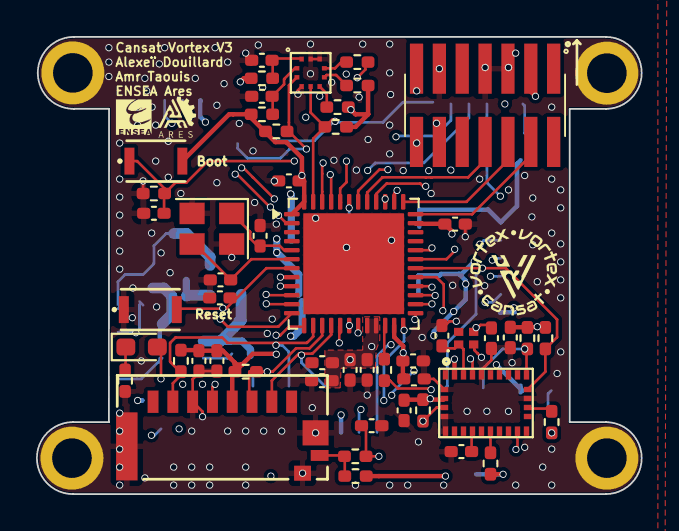
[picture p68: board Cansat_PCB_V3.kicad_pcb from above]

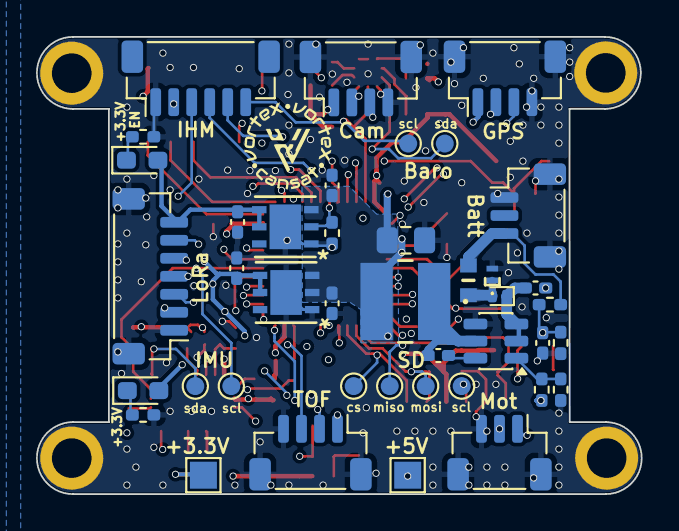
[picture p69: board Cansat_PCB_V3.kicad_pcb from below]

Board: 6 copper layers, 33.6 x 25.4 mm, 96 parts (41 on the bottom side), 63 nets.

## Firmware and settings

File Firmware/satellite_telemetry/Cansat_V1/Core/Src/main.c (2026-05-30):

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
/* Includes ------------------------------------------------------------------*/
#include "main.h"
#include "cmsis_os.h"
#include "app_fatfs.h"

/* USER CODE BEGIN Includes */
#include <stdio.h>
#include <string.h>
#include <math.h>
#include "math.h"

#include "File_Handling_RTOS.h"
#include "File_Handling_RTOS.h"

// Devices
#include "bmp581.h"
#include "lidar.h"
#include "cansat_core.h"
#include "imu.h"
#include "sx1276.h"
#include "gnss_reader.h"
#include "hmi.h"
/* USER CODE END Includes */

ADC_HandleTypeDef hadc1;

I2C_HandleTypeDef hi2c1;
I2C_HandleTypeDef hi2c3;
DMA_HandleTypeDef hdma_i2c1_tx;
DMA_HandleTypeDef hdma_i2c1_rx;
DMA_HandleTypeDef hdma_i2c3_rx;

SPI_HandleTypeDef hspi1;
SPI_HandleTypeDef hspi2;

TIM_HandleTypeDef htim1;
TIM_HandleTypeDef htim3;
TIM_HandleTypeDef htim16;

UART_HandleTypeDef huart1;
UART_HandleTypeDef huart3;
DMA_HandleTypeDef hdma_usart3_rx;

/* Definitions for TaskFSM */
osThreadId_t TaskFSMHandle;
const osThreadAttr_t TaskFSM_attributes = {
  .name = "TaskFSM",
  .priority = (osPriority_t) osPriorityNormal,
  .stack_size = 256 * 4
};
/* Definitions for TaskSensors */
osThreadId_t TaskSensorsHandle;
const osThreadAttr_t TaskSensors_attributes = {
  .name = "TaskSensors",
  .priority = (osPriority_t) osPriorityAboveNormal1,
  .stack_size = 512 * 4
};
/* Definitions for TaskSDCard */
osThreadId_t TaskSDCardHandle;
const osThreadAttr_t TaskSDCard_attributes = {
  .name = "TaskSDCard",
  .priority = (osPriority_t) osPriorityAboveNormal,
  .stack_size = 1024 * 4
};
/* Definitions for TaskLoRa */
osThreadId_t TaskLoRaHandle;
const osThreadAttr_t TaskLoRa_attributes = {
  .name = "TaskLoRa",
  .priority = (osPriority_t) osPriorityLow,
  .stack_size = 512 * 4
};
/* Definitions for TaskHMIHandle */
osThreadId_t TaskHMIHandleHandle;
const osThreadAttr_t TaskHMIHandle_attributes = {
  .name = "TaskHMIHandle",
  .priority = (osPriority_t) osPriorityHigh,
  .stack_size = 1024 * 4
};
/* Definitions for I2C1_Mutex */
osMutexId_t I2C1_MutexHandle;
const osMutexAttr_t I2C1_Mutex_attributes = {
  .name = "I2C1_Mutex"
};
/* USER CODE BEGIN PV */
// Flight session number (auto-incremented at boot based on existing files)
uint8_t flight_session = 1;
char data_filename[16];    // e.g. "DATA_001.CSV"
char lidar_filename[16];   // e.g. "LIDAR_001.CSV"
uint8_t is_calibrated = 0;

uint8_t TX_to_Baro [] = "A" ;
uint8_t RX_from_Baro [] = "A" ;

extern volatile uint8_t FatFsCnt;
extern void SDTimer_Handler(void);
FIL fil_lidar;
uint8_t lidar_file_open = 0;

// --- GLOBAL VARIABLES (Accessible by all tasks) ---
volatile uint8_t configFlag = 1; // Triggered by external switch/button
CanSatState_t currentState = STATE_STANDBY;
float current_height = 0.0f;
uint8_t imu_is_connected = 0;
uint32_t calibration_duration_ms = 0;

// Global Sensor Data
GNSS_Data_t latest_gnss;
Barometer_Data_t latest_baro;
IMU_Data_t latest_imu;
LIDAR_Data_t latest_lidar = { .distance = 99.0f };
BMP_t bmp_sensor;
Battery_Data_t latest_battery;
extern HMI_Display_Data_t HMI_display_data;
// Lidar variables to handle the DMA and broken DMA parts
char lidar_cut_char[32] = {0};
uint8_t cut_char_len = 0;
extern uint8_t lidar_dma_buf[];

//IMU Variables for the DMA
uint8_t imu_dma_rx_buf[34];
// Calibration Variables
double reference_pressure_Pa = 101325.0;
double reference_temp_C = 25.0;
double PRESS_TEMP_COEF = -8.5; // Datasheet: Pressure Temperature-induced offset: +-0.5 Pa/K

// Queue Handles
QueueHandle_t qSensorEvents;
QueueHandle_t qSDCard;
QueueHandle_t qLoRa;
QueueHandle_t qSDCard_LIDAR;  // High-frequency LIDAR-only queue (50 Hz)
QueueHandle_t qHMI_Events;
/* USER CODE END PV */

void SystemClock_Config(void);
static void MX_GPIO_Init(void);
static void MX_DMA_Init(void);
static void MX_USART1_UART_Init(void);
static void MX_I2C1_Init(void);
static void MX_ADC1_Init(void);
static void MX_I2C3_Init(void);
static void MX_SPI2_Init(void);
static void MX_TIM3_Init(void);
static void MX_USART3_UART_Init(void);
static void MX_SPI1_Init(void);
static void MX_TIM1_Init(void);
static void MX_TIM16_Init(void);
void startTaskFSM(void *argument);
void startTaskSensors(void *argument);
void startTaskSDCard(void *argument);
void startTaskLoRa(void *argument);
void startTaskHMI(void *argument);

/* USER CODE BEGIN 0 */
int _write(int file, char *ptr, int len) {
    HAL_UART_Transmit(&huart1, (uint8_t*)ptr, len, HAL_MAX_DELAY);
    return len;
}
uint8_t debug = 1;
/* USER CODE END 0 */

/**
  * @brief  The application entry point.
  * @retval int
  */
int main(void)
{

  /* USER CODE BEGIN 1 */
	//__disable_irq(); //to avoid crash but it also disables interrupts for uart
  /* USER CODE END 1 */

  /* MCU Configuration--------------------------------------------------------*/

  /* Reset of all peripherals, Initializes the Flash interface and the Systick. */
  HAL_Init();

  /* Configure the system clock */
  SystemClock_Config();

  /* USER CODE BEGIN SysInit */
  __HAL_RCC_USART3_FORCE_RESET();
    __HAL_RCC_USART1_FORCE_RESET();

    // 2. On attend quelques millisecondes que les condensateurs internes se vident
    HAL_Delay(10);

    // 3. On relâche le Reset pour les laisser s'allumer proprement
    __HAL_RCC_USART3_RELEASE_RESET();
    __HAL_RCC_USART1_RELEASE_RESET();
  /* USER CODE END SysInit */

  /* Initialize all configured peripherals */
  MX_GPIO_Init();
  MX_DMA_Init();
  MX_USART1_UART_Init();
  MX_I2C1_Init();
  MX_ADC1_Init();
  MX_I2C3_Init();
  MX_SPI2_Init();
  MX_TIM3_Init();
  MX_USART3_UART_Init();
  MX_SPI1_Init();
  MX_TIM1_Init();
  if (MX_FATFS_Init() != APP_OK) {
    Error_Handler();
  }
  MX_TIM16_Init();
  /* USER CODE BEGIN 2 */

  // --- 1. POWER ON LORA AND SENSORS ---
    //HAL_GPIO_WritePin(VPOWER_EN_GPIO_OUT_GPIO_Port, VPOWER_EN_GPIO_OUT_Pin, GPIO_PIN_SET);

    // --- 2. FIX SPI CHIP SELECT (NSS) ---
    //NSS must idle HIGH. If it starts LOW, the SPI bus crashes.
    HAL_GPIO_WritePin(GPIOB, LORA_NSS_Pin, GPIO_PIN_SET);

    char startup_msg[] = "\r\n[i] System Booting... Testing Hardware\r\n";
    HAL_UART_Transmit(&huart1, (uint8_t*)startup_msg, strlen(startup_msg), HAL_MAX_DELAY);
    HAL_Delay(2000);
  // --- BATTERY VOLTAGE CHECK (ADC1) ---
    char adc_msg[128];
    sprintf(adc_msg, "\r\n[*] Testing Power (ADC1)...\r\n");
    HAL_UART_Transmit(&huart1, (uint8_t*)adc_msg, strlen(adc_msg), 100);

    // Start ADC Conversion
    HAL_ADC_Start(&hadc1);

    // Wait up to 100ms for the conversion to finish
    if (HAL_ADC_PollForConversion(&hadc1, 100) == HAL_OK) {
        uint32_t raw_adc = HAL_ADC_GetValue(&hadc1);

        // Calculate voltage directly at the STM32 pin (12-bit ADC, 3.3V ref)
        float pin_voltage = ((float)raw_adc / 4095.0f) * 3.3f;

        // --- VOLTAGE DIVIDER RATIO ---
        // IMPORTANT: Adjust this multiplier to match your physical PCB resistors!
        // Example: A 10k/10k divider cuts voltage in half, so the ratio is 2.0f.
        // Example: A 20k/10k divider cuts voltage to a third, so the ratio is 3.0f.
        float voltage_divider_ratio = 3.0f; // <-- CHANGE THIS TO MATCH YOUR HARDWARE

        float true_battery_voltage = pin_voltage * voltage_divider_ratio*1.025f;

        // Séparation en partie entière et partie décimale (2 chiffres après la virgule)
        int part_ent = (int)true_battery_voltage;
        int part_dec = (int)((true_battery_voltage - part_ent) * 100);

        // On utilise %d pour les entiers et %02d pour forcer l'affichage du zéro (ex: 8.05V)
        sprintf(adc_msg, "    -> SUCCESS! Battery: %d.%02d V (Raw ADC: %lu)\r\n", part_ent, part_dec, raw_adc);
        HAL_UART_Transmit(&huart1, (uint8_t*)adc_msg, strlen(adc_msg), 100);
    }
    // Stop the ADC to save power
    HAL_ADC_Stop(&hadc1);
    // ------------------------------------
  // --- I2C SCANNER ---
    char scan_msg[64];
    sprintf(scan_msg, "\r\n[*] Scanning I2C Bus 1...\r\n");
    HAL_UART_Transmit(&huart1, (uint8_t*)scan_msg, strlen(scan_msg), 100);

    for(uint8_t i = 1; i < 128; i++) {
        // Shift the address left by 1 for the HAL library
        if(HAL_I2C_IsDeviceReady(&hi2c1, (uint16_t)(i<<1), 3, 5) == HAL_OK) {
            sprintf(scan_msg, "    -> Found device at address: 0x%02X\r\n", i);
            HAL_UART_Transmit(&huart1, (uint8_t*)scan_msg, strlen(scan_msg), 100);
        }
    }

    sprintf(scan_msg, "\r\n[*] Scanning I2C Bus 3...\r\n");
    HAL_UART_Transmit(&huart1, (uint8_t*)scan_msg, strlen(scan_msg), 100);
    for(uint8_t i = 1; i < 128; i++) {
        // Shift the address left by 1 for the HAL library
        if(HAL_I2C_IsDeviceReady(&hi2c3, (uint16_t)(i<<1), 3, 5) == HAL_OK) {
            sprintf(scan_msg, "    -> Found device at address: 0x%02X\r\n", i);
            HAL_UART_Transmit(&huart1, (uint8_t*)scan_msg, strlen(scan_msg), 100);
        }
    }
    sprintf(scan_msg, "[*] Scan Complete.\r\n\r\n");
    HAL_UART_Transmit(&huart1, (uint8_t*)scan_msg, strlen(scan_msg), 100);
    // -----------------------------


    // --- UART3 DIAGNOSTIC PING ---
        char diag_msg[128];
        // 1. Print the STM32's configured Baud Rate
        sprintf(diag_msg, "    -> STM32 UART3 BaudRate: %lu\r\n", huart3.Init.BaudRate);
        HAL_UART_Transmit(&huart1, (uint8_t*)diag_msg, strlen(diag_msg), 100);

        // 2. Clear any old data out of the STM32 buffer
        __HAL_UART_FLUSH_DRREGISTER(&huart3);

        // 3. Send a Spacebar (' ') to attempt to wake up the LiDAR menu
        uint8_t test_tx = ' ';
        HAL_UART_Transmit(&huart3, &test_tx, 1, 100);

        // 4. Wait up to 500ms for the LiDAR to reply
        uint8_t test_rx[1] = {0};
        HAL_StatusTypeDef uart_status = HAL_UART_Receive(&huart3, test_rx, 1, 500);



        if (uart_status == HAL_OK) {
            // We received a byte! Let's see if it is a readable ASCII character.
            if (test_rx[0] >= 32 && test_rx[0] <= 126) {
                sprintf(diag_msg, "    -> SUCCESS! Received valid ASCII: '%c' (0x%02X)\r\n\n", test_rx[0], test_rx[0]);
            } else {
                sprintf(diag_msg, "    -> WARNING! Received garbage byte: 0x%02X (Baud rate mismatch?)\r\n\n", test_rx[0]);
            }
            HAL_UART_Transmit(&huart1, (uint8_t*)diag_msg, strlen(diag_msg), 100);
        } else {
            sprintf(diag_msg, "    -> FAILED! No response from LiDAR. (Check TX/RX wiring)\r\n\n");
            HAL_UART_Transmit(&huart1, (uint8_t*)diag_msg, strlen(diag_msg), 100);
        }


        // -----------------------------


  // Initialize Barometer
  if (bmp581_init_precise_normal(&bmp_sensor) == 0) {
	  char baro_msg[] = "[+] BMP581 Initialized Successfully\r\n";
	  HAL_UART_Transmit(&huart1, (uint8_t*)baro_msg, strlen(baro_msg), HAL_MAX_DELAY);
  } else {
	  char baro_msg[] = "[-] BMP581 Initialization FAILED\r\n";
	  HAL_UART_Transmit(&huart1, (uint8_t*)baro_msg, strlen(baro_msg), HAL_MAX_DELAY);
  }

  // Initialize IMU
  if (IMU_Init(&hi2c3) == 1) {
        imu_is_connected = 1; // Mark as successful
        char imu_msg[] = "[+] BNO055 Initialized Successfully\r\n";
        HAL_UART_Transmit(&huart1, (uint8_t*)imu_msg, strlen(imu_msg), HAL_MAX_DELAY);
    } else {
        imu_is_connected = 0; // Mark as failed
        char imu_msg[] = "[-] BNO055 Initialization FAILED\r\n";
        HAL_UART_Transmit(&huart1, (uint8_t*)imu_msg, strlen(imu_msg), HAL_MAX_DELAY);
    }

  char vortex_art[] =
	"\r\n"
	"---------------------------------------------------------------\r\n"
	" __     __         _               ___  ____  \r\n"
	" \\ \\   / /__  _ __| |_ _____  __  / _ \\/ ___| \r\n"
	"  \\ \\ / / _ \\| '__| __/ _ \\ \\/ / | | | \\___ \\ \r\n"
	"   \\ V / (_) | |  | ||  __/>  <  | |_| |___) |\r\n"
	"    \\_/ \\___/|_|   \\__\\___/_/\\_\\  \\___/|____/ \r\n"
	"---------------------------------------------------------------\r\n"
	"\r\n[i] Starting RTOS...\r\n\r\n";

	HAL_UART_Transmit(&huart1, (uint8_t*)vortex_art, strlen(vortex_art), HAL_MAX_DELAY);




	// Initialize background GNSS listening on USART1
	char gnss_init_msg[] = "[*] Arming GNSS Interrupt...\r\n";
	HAL_UART_Transmit(&huart1, (uint8_t*)gnss_init_msg, strlen(gnss_init_msg), 100);

	//================================================================================For debugging purposes i put GNSS initialisation in comment
	if (debug==0){
		GNSS_Init();
	}

	char startup2_msg[] = "\r\n[i] System Booting... Testing Hardware\r\n";
	HAL_UART_Transmit(&huart1, (uint8_t*)startup2_msg, strlen(startup2_msg), HAL_MAX_DELAY);
  /* USER CODE END 2 */

  /* Init scheduler */
  osKernelInitialize();
  /* Create the mutex(es) */
  /* creation of I2C1_Mutex */
  I2C1_MutexHandle = osMutexNew(&I2C1_Mutex_attributes);

  /* USER CODE BEGIN RTOS_MUTEX */
  /* add mutexes, ... */
  /* USER CODE END RTOS_MUTEX */

  /* USER CODE BEGIN RTOS_SEMAPHORES */
  /* add semaphores, ... */
  /* USER CODE END RTOS_SEMAPHORES */

  /* USER CODE BEGIN RTOS_TIMERS */
  /* start timers, add new ones, ... */
  /* USER CODE END RTOS_TIMERS */

  /* USER CODE BEGIN RTOS_QUEUES */
    // MUST CREATE THE QUEUES BEFORE STARTING THE TASKS
    qSensorEvents = xQueueCreate(10, sizeof(SensorEvent_t));
    qSDCard       = xQueueCreate(5, sizeof(TelemetryPacket_t));
    qLoRa         = xQueueCreate(5,  sizeof(TelemetryPacket_t));
    qSDCard_LIDAR = xQueueCreate(100, sizeof(LidarPacket_t));  // Larger buffer for 50Hz
    qHMI_Events = xQueueCreate(10, sizeof(uint8_t));
  /* USER CODE END RTOS_QUEUES */

  /* Create the thread(s) */
  /* creation of TaskFSM */
  TaskFSMHandle = osThreadNew(startTaskFSM, NULL, &TaskFSM_attributes);

  /* creation of TaskSensors */
  TaskSensorsHandle = osThreadNew(startTaskSensors, NULL, &TaskSensors_attributes);

  /* creation of TaskSDCard */
  TaskSDCardHandle = osThreadNew(startTaskSDCard, NULL, &TaskSDCard_attributes);

  /* creation of TaskLoRa */
  TaskLoRaHandle = osThreadNew(startTaskLoRa, NULL, &TaskLoRa_attributes);

  /* creation of TaskHMIHandle */
  TaskHMIHandleHandle = osThreadNew(startTaskHMI, NULL, &TaskHMIHandle_attributes);

  /* USER CODE BEGIN RTOS_THREADS */
  /* add threads, ... */
  /* USER CODE END RTOS_THREADS */

  /* USER CODE BEGIN RTOS_EVENTS */
  /* add events, ... */

  /* USER CODE END RTOS_EVENTS */

  /* Start scheduler */
  osKernelStart();

  /* We should never get here as control is now taken by the scheduler */

  /* Infinite loop */
  /* USER CODE BEGIN WHILE */
  while (1)
  {
    /* USER CODE END WHILE */

    /* USER CODE BEGIN 3 */

  }
  /* USER CODE END 3 */
}

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
/* USER CODE BEGIN 4 */

// ========== CALLBACK EXTI BOUTON PA3 ==========

static uint32_t last_button_press = 0;
#define DEBOUNCE_DELAY_MS 200
void HAL_GPIO_EXTI_Callback(uint16_t GPIO_Pin)
{
    if (GPIO_Pin == GPIO_PIN_3) {
        uint32_t now = HAL_GetTick();

        if (now - last_button_press < DEBOUNCE_DELAY_MS) {
            return;
        }
        last_button_press = now;
// Protections to not write if we are not ready to recieve
        if (qHMI_Events != NULL) {
                    BaseType_t xHigherPriorityTaskWoken = pdFALSE;
                    uint8_t event = 1;
                    xQueueSendFromISR(qHMI_Events, &event, &xHigherPriorityTaskWoken);
                    portYIELD_FROM_ISR(xHigherPriorityTaskWoken);
                }
    }
}

void HAL_I2C_MemRxCpltCallback(I2C_HandleTypeDef *hi2c)
{
    // Si c'est l'I2C de notre IMU (I2C3) qui a terminé son DMA
    if (hi2c->Instance == I2C3) {

        // On horodate précisément la mesure à l'instant où elle arrive
        sprintf(latest_imu.timestamp, "%lu", HAL_GetTick());

        // On demande à notre driver de transformer le buffer brut en données exploitables
        IMU_ProcessData_DMA(&latest_imu);
    }
}

/**
 * @brief Convertit un float en string sans sprintf (évite heap overflow)
 * @param value Float à convertir
 * @param decimals Nombre de décimales (1, 2, ou 6)
 * @param buffer Buffer de sortie (min 16 bytes)
 *
 * Exemple: float_to_str(7.42, 2, buf) → "7.42"
 *          float_to_str(-123.5, 1, buf) → "-123.5"
 */
void float_to_str(float value, uint8_t decimals, char* buffer)
{
    int idx = 0;

    // Gestion signe négatif
    if (value < 0) {
        buffer[idx++] = '-';
        value = -value;
    }

    // Partie entière
    int int_part = (int)value;

    // Convertir partie entière en string (manuellement)
    if (int_part == 0) {
        buffer[idx++] = '0';
    } else {
        char temp[12];
        int temp_idx = 0;
        int num = int_part;

        while (num > 0) {
            temp[temp_idx++] = '0' + (num % 10);
            num /= 10;
        }

        // Inverser (car on a construit à l'envers)
        for (int i = temp_idx - 1; i >= 0; i--) {
            buffer[idx++] = temp[i];
        }
    }

    // Point décimal
    if (decimals > 0) {
        buffer[idx++] = '.';

        // Partie décimale
        float dec_part = value - int_part;

        for (uint8_t i = 0; i < decimals; i++) {
            dec_part *= 10;
            int digit = (int)dec_part;
            buffer[idx++] = '0' + digit;
            dec_part -= digit;
        }
    }

    buffer[idx] = '\0';
}

/* USER CODE BEGIN 4 */

// ... tes autres callbacks existants ...

void HAL_UART_ErrorCallback(UART_HandleTypeDef *huart)
{
    // Routage vers le module GNSS (USART1)
    if (huart->Instance == USART1) {
        GNSS_UART_Error_Handler(huart);
    }

    // Routage vers le module LiDAR (USART3)
    else if (huart->Instance == USART3) {
        Lidar_UART_Error_Handler(huart);
    }
}

/* USER CODE END 4 */
/*
void HAL_UART_RxCpltCallback(UART_HandleTypeDef *huart) {
    // Route UART3 interrupts directly to the LiDAR driver
    if (huart->Instance == USART3) {
        Lidar_RxCallback(huart);
    }

    // Route UART2 interrupts directly to the GNSS driver
    if (huart->Instance == USART1) {
        GNSS_UART_RxCpltCallback(huart);
    }
}

*/
/* USER CODE END 4 */
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

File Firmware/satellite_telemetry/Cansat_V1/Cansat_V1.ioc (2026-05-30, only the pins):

Mcu.UserName=STM32G431CBUx
PA10.GPIO_Label=STLINK_GPS_USART1-RX
PA10.Signal=USART1_RX
PA13.Signal=SYS_JTMS-SWDIO
PA14.Signal=SYS_JTCK-SWCLK
PA15.GPIO_Label=BARO_I2C1_SCL
PA15.Signal=I2C1_SCL
PA2.GPIO_Label=VBAT_ADC1_IN3
PA2.Signal=ADC1_IN3
PA3.GPIO_Label=HMIBTN_EXTI3
PA3.Signal=GPXTI3
PA4.GPIO_Label=BARO_EXTI
PA4.Signal=GPXTI4
PA5.GPIO_Label=SD_SPI1_SCK
PA5.Signal=SPI1_SCK
PA6.GPIO_Label=SD_SPI1_MISO
PA6.Signal=SPI1_MISO
PA7.GPIO_Label=SD_SPI1_MOSI
PA7.Signal=SPI1_MOSI
PA8.GPIO_Label=IMU_I2C3_SCL
PA8.Signal=I2C3_SCL
PA9.GPIO_Label=STLINK_GPS_USART1-TX
PA9.Signal=USART1_TX
PB0.GPIO_Label=LED_GPIO_OUT
PB0.Signal=GPIO_Output
PB10.GPIO_Label=HMILED_GPIO
PB10.Signal=GPIO_Output
PB11.GPIO_Label=LIDAR_USART3_RX
PB11.Signal=USART3_RX
PB12.GPIO_Label=LORA_NSS
PB12.Signal=GPIO_Output
PB13.GPIO_Label=LORA_SPI2_SCK
PB13.Signal=SPI2_SCK
PB14.GPIO_Label=LORA_SPI2_MISO
PB14.Signal=SPI2_MISO
PB15.GPIO_Label=LORA_SPI2_MOSI
PB15.Signal=SPI2_MOSI
PB2.GPIO_Label=SD_GPIO_DETECT
PB2.Signal=GPIO_Input
PB3.Signal=SYS_JTDO-SWO
PB4.GPIO_Label=LORA_RST
PB4.Signal=GPIO_Output
PB5.GPIO_Label=VPOWER_EN_GPIO_OUT
PB5.Signal=GPIO_Output
PB9.GPIO_Label=BARO_I2C1_SDA
PB9.Signal=I2C1_SDA
PC10.GPIO_Label=LIDAR_USART3_TX
PC10.Signal=USART3_TX
PC11.GPIO_Label=IMU_I2C3_SDA
PC11.Signal=I2C3_SDA
PC4.GPIO_Label=SD_GPIO_CS
PC4.Signal=GPIO_Output
PC6.GPIO_Label=MOTOR_TIM3_CH1
PC6.Signal=S_TIM3_CH1
PF0-OSC_IN.Signal=RCC_OSC_IN
PF1-OSC_OUT.Signal=RCC_OSC_OUT

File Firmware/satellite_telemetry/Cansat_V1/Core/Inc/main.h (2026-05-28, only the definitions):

#define VBAT_ADC1_IN3_Pin GPIO_PIN_2
#define VBAT_ADC1_IN3_GPIO_Port GPIOA
#define HMIBTN_EXTI3_Pin GPIO_PIN_3
#define HMIBTN_EXTI3_GPIO_Port GPIOA
#define HMIBTN_EXTI3_EXTI_IRQn EXTI3_IRQn
#define BARO_EXTI_Pin GPIO_PIN_4
#define BARO_EXTI_GPIO_Port GPIOA
#define SD_SPI1_SCK_Pin GPIO_PIN_5
#define SD_SPI1_SCK_GPIO_Port GPIOA
#define SD_SPI1_MISO_Pin GPIO_PIN_6
#define SD_SPI1_MISO_GPIO_Port GPIOA
#define SD_SPI1_MOSI_Pin GPIO_PIN_7
#define SD_SPI1_MOSI_GPIO_Port GPIOA
#define SD_GPIO_CS_Pin GPIO_PIN_4
#define SD_GPIO_CS_GPIO_Port GPIOC
#define LED_GPIO_OUT_Pin GPIO_PIN_0
#define LED_GPIO_OUT_GPIO_Port GPIOB
#define SD_GPIO_DETECT_Pin GPIO_PIN_2
#define SD_GPIO_DETECT_GPIO_Port GPIOB
#define HMILED_GPIO_Pin GPIO_PIN_10
#define HMILED_GPIO_GPIO_Port GPIOB
#define LIDAR_USART3_RX_Pin GPIO_PIN_11
#define LIDAR_USART3_RX_GPIO_Port GPIOB
#define LORA_NSS_Pin GPIO_PIN_12
#define LORA_NSS_GPIO_Port GPIOB
#define LORA_SPI2_SCK_Pin GPIO_PIN_13
#define LORA_SPI2_SCK_GPIO_Port GPIOB
#define LORA_SPI2_MISO_Pin GPIO_PIN_14
#define LORA_SPI2_MISO_GPIO_Port GPIOB
#define LORA_SPI2_MOSI_Pin GPIO_PIN_15
#define LORA_SPI2_MOSI_GPIO_Port GPIOB
#define MOTOR_TIM3_CH1_Pin GPIO_PIN_6
#define MOTOR_TIM3_CH1_GPIO_Port GPIOC
#define IMU_I2C3_SCL_Pin GPIO_PIN_8
#define IMU_I2C3_SCL_GPIO_Port GPIOA
#define STLINK_GPS_USART1_TX_Pin GPIO_PIN_9
#define STLINK_GPS_USART1_TX_GPIO_Port GPIOA
#define STLINK_GPS_USART1_RX_Pin GPIO_PIN_10
#define STLINK_GPS_USART1_RX_GPIO_Port GPIOA
#define BARO_I2C1_SCL_Pin GPIO_PIN_15
#define BARO_I2C1_SCL_GPIO_Port GPIOA
#define LIDAR_USART3_TX_Pin GPIO_PIN_10
#define LIDAR_USART3_TX_GPIO_Port GPIOC
#define IMU_I2C3_SDA_Pin GPIO_PIN_11
#define IMU_I2C3_SDA_GPIO_Port GPIOC
#define LORA_RST_Pin GPIO_PIN_4
#define LORA_RST_GPIO_Port GPIOB
#define VPOWER_EN_GPIO_OUT_Pin GPIO_PIN_5
#define VPOWER_EN_GPIO_OUT_GPIO_Port GPIOB
#define BARO_I2C1_SDA_Pin GPIO_PIN_9
#define BARO_I2C1_SDA_GPIO_Port GPIOB

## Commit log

2025-10-25 Update README.md
    Strategy update : explanations of the current rules and added link to the Onshape folder
2025-12-15 PCB_V1 added to main branch it is not a merge because the branch had encountered some issues and it required fixing without a git history
    [BM03B-SRSS-TB.STEP, BM04B-SRSS-TB.STEP, BM07B-SRSS-TB.STEP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]
2026-01-13 Added schematic images to the IMG folder
2026-04-13 PCB_V2 added (not a merge to avoid conflicts)
    [Cansat_PCB.kicad_pcb, Cansat_PCB.kicad_sch, Cansat_PCB.step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]
2026-04-13 PCB_V3 added (not a merge to avoid conflicts)
    [Cansat_PCB_V3.kicad_pcb, Cansat_PCB_V3.kicad_sch, Cansat_PCB_V3.step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]
2026-04-13 importing new readme
    [Cansat_PCB_V3.kicad_pcb, Cansat_PCB_V3.kicad_sch, connectique_et_alimentation.kicad_sch]
2026-04-14 added the UART2 for the camera as well as M2 holes
    [Cansat_PCB_V3.kicad_pcb, Cansat_PCB_V3.kicad_sch, connectique_et_alimentation.kicad_sch]
2026-04-14 added marking to the testpoints
    [Cansat_PCB_V3.kicad_pcb]
2026-04-15 Add Button_Screen2 image to README
    Added a new image for the button pushed state in the README.
2026-04-15 Fix wording and clarify HMI PCB testing details
2026-04-21 mega big readme update for the mechanical and wind tunnel parts
    [0467001.NRHF.stp, Cansat_PCB_V3.kicad_pcb, SPHV12-01ETG.stp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]
2026-04-22 updated readme and uploaded firmware section
    [Cansat_V1 Debug.cfg]
2026-05-13 added GUI
    [Corps.stl, Corps1.stl]
2026-05-15 SD Card Working, implementation of the Lidar in progress
2026-05-28 code update with lidar.csv, IHM
2026-05-28 fixed LIDAR.csv issues
2026-05-28 added lidar condition
2026-05-29 starting implementation of the new code : known issue freeze after a few seconds we suspect a memory overflow
    [Cansat_V1.ioc, File_Handling_RTOS.c, hmi.c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]
2026-05-30 finally solved the bug that breaks the lidar when the power is turned off and on, as well as some fixes for the new formating ability
    [Cansat_V1.ioc, gnss_reader.c, hmi.c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]

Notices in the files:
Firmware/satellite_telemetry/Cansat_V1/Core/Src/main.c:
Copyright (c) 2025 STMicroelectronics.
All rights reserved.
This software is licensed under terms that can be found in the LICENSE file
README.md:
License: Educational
